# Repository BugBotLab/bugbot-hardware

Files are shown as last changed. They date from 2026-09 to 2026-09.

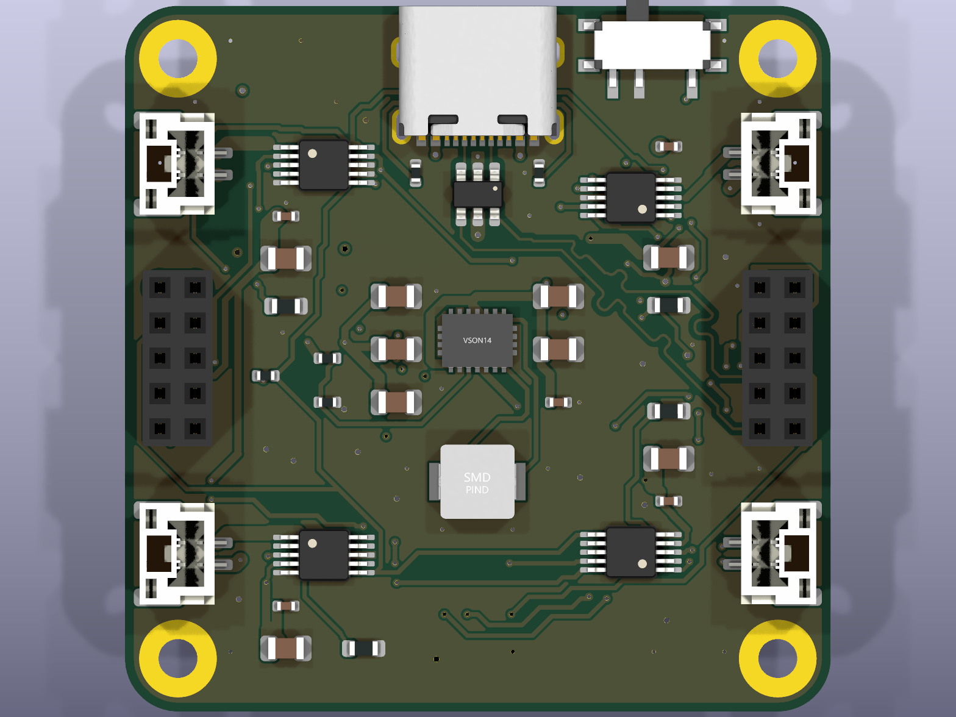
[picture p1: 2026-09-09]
design/3d/BugBot_Motion_Board_top.png

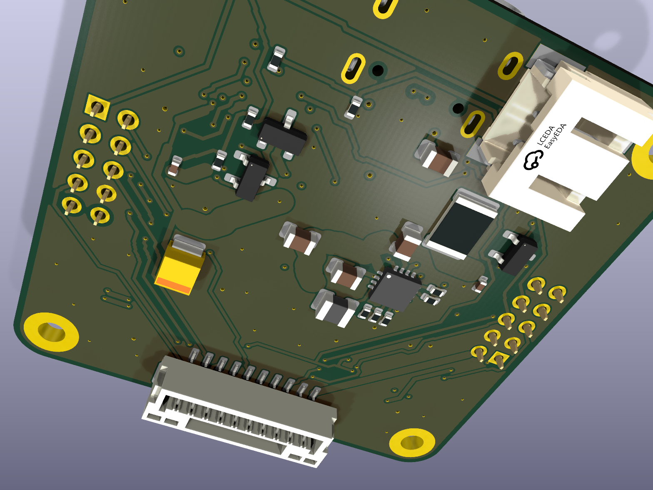
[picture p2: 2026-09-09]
design/3d/BugBot_Motion_Board_iso_bottom.png

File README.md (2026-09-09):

# bugbot-hardware

Everything physical about BugBot: the schematics, the bill of materials, 3D models of the robot and its boards, the assembly guide, and the circuit simulation bench that doubles as the schematics' test suite.

Part of the [BugBot open-source plan](https://github.com/BugBotLab).

## What is public and what is not

The **schematics are public**: every sheet as KiCad source and as PDF, the symbol library, the netlists, and the BOM with part numbers. Anyone can read, simulate and repair every circuit.

The **PCB layout is not published**: no `.kicad_pcb`, no gerbers, no pick-and-place files. The 3D models here were exported without copper, so they show the boards and their parts but not the routing.

## The robot

Three 40 x 40 mm boards stacked on 2 x 5 sockets, on a 3D-printed chassis, moving by four vibration motors on a silicone mat:

| Board | Does |
|---|---|
| Motion | battery, USB-C charging, 3.3 V rail, four DRV8830 motor drivers, two servo outputs, the ToF module connector |
| Vision | ESP32-P4 (plus its C6 for Wi-Fi), OV5647 camera on a 22-pin flex, power switch, boot and reset buttons, LED |
| Odometry | PMW3360 optical-flow sensor and BNO055 IMU, on a 10-way cable to Motion |

## Layout

| path | what |
|---|---|
| `design/schematics/<Board>/` | KiCad schematic sheets, `BugBot.kicad_sym`, the project file, `golden_netlist.xml`, and the schematic PDF |
| `design/bom/` | `BugBot_BOM.xlsx` (parts, per-board sheets, costing, flags) and the JLCPCB BOM CSVs |
| `design/3d/` | `.step` and `.glb` of each board without copper, plus renders |
| `design/mechanical/` | chassis and mat (see its README for where the CAD lives today) |
| `sim/` | the circuit bench: ngspice simulation of the whole stack from the netlists, 89 static checks, scenario runs, and an interactive schematic bench. See `sim/README.md` |
| `docs/` | assembly and bring-up |
| `viewer/` | a web page that spins the board models (uses the `.glb` files), hosted at https://www.bugbotlab.com/bugbot-hardware/viewer/ |

## Simulation is the schematic test suite

`sim/` builds a SPICE model of the three boards from `golden_netlist.xml` and checks it against the datasheets: rails, currents, USB limits, no-cell behaviour, motor stalls. When a schematic changes, `python sim/tools/sync_boards.py` refreshes the snapshot and `python sim/check_static.py` plus `python sim/sim_stack.py` say whether it still holds. That is why the bench lives in this repo rather than beside the firmware.

Needs KiCad 10 installed (for ngspice and kicad-cli).

## Licence

MIT, BugBotLab Ltd. Hardware files under the same licence.

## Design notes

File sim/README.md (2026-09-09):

# bugbot_sim

Circuit simulation of the BugBot stack (Motion board + Vision board + Odometry
board) from the real KiCad netlists, using KiCad's bundled ngspice. Every
component value and every connection comes from `golden_netlist.xml`; the ICs
are behavioural models built from their datasheets (`models/stack_models.lib`,
numbers and sources in `parts_spec.py`). Motors are electromechanical, the MCU
is a scripted list of I2C register writes. The Motion and Vision boards join
pin-for-pin at the J8/J9 stack sockets; the Odometry board hangs on the Motion
J7 GH1.25 cable (J7 pin k to J1 pin 11-k since the 2026-09-07 mirror, 120 mOhm per conductor) with its 1.9 V LDO,
the PMW3360 and the BNO055 modelled as loads (added 2026-09-06).

## Run

```
python sim_stack.py        # scenarios A-P (DC, transient, no-cell, USB limits) + datasheet spec checks (~2 min)
python sim_mission.py      # drive / stall / USB missions with running motors (~3 min)
MOTOR=N20_geared_3v python sim_mission.py     # other motor types: see parts_spec.MOTOR_TYPES
python bench/server.py     # interactive schematic bench at http://localhost:8765
python tools/sync_boards.py   # refresh boards/ from the KiCad projects (BUGBOT_HW env)
```

Needs KiCad 10 installed (ngspice.dll, kicad-cli, symbol library). Override with
`NGSPICE_DLL` or `KICAD_DIR`.

## Layout

| path | what |
|---|---|
| `boards/<motion,vision,odometry>/` | snapshot of each project: golden netlist, schematic sheets, sheet SVGs |
| `models/` | SPICE behavioural models (`stack_models.lib` is the current one) |
| `netlist2spice.py` | golden netlist -> SPICE elements, the only source of connectivity |
| `stack_build.py` | the shared deck: Motion + Vision joined at J8/J9, Odometry on the J7 cable, loads, motors, servos |
| `parts_spec.py` | datasheet limits per part, motor types |
| `sim_stack.py` | scenarios A..M and spec checks, prints DESIGN FINDINGS |
| `sim_mission.py` | time-domain missions, writes `out/mission_*.json` |
| `sch_geometry.py` | every wire / pin of every sheet tied to its net (for the bench) |
| `bench/` | interactive viewer: click the switch, USB, motors; ngspice re-solves |
| `legacy/` | the first single-board testbenches (pre-respin Motion, Vision only) |

## Field solver

The openEMS field-solver experiments (impedance and emissions from the PCB layout) are not in this repository: they work from the layout files, which are not published.

## What the simulation can and cannot see

`sim_stack.py` starts with `check_static.py`: every IC pin against its
CONFIRMED datasheet pin table (`parts_spec.PARTS[...]["pinout"]`), the
DRV8830 address straps (unique addresses), the I2C pull-ups, the FB divider,
the charger's ENB/USB_DET/ENPPB/ISET straps, floating inputs. This exists
because the DRV8830 pinout error of 2026-09-04 passed every ngspice scenario:
the sim and the schematic shared the same wrong pin table. A netlist-driven
sim proves board = schematic, not schematic = datasheet.

Still approximate, on purpose:
- the regulators and the H-bridges are average (non-switching) models; the
  inductor checks add the 2.4 MHz / 3 MHz ripple analytically, capacitor
  ripple current is not checked
- an operating point that ngspice cannot converge is taken from a ramped
  transient and counted in the summary line ("N operating point(s) from
  ramped transients"); a real instability would look the same
- the PTC is a resistor: the harness checks the cell current against its
  3 A hold, it never trips in the model
- loads are constant currents except the Wi-Fi burst scenario (N) and the
  missions; the ToF and camera are their typical currents; the Odometry
  board's PMW3360 draws the datasheet's run4 figure (37 mA including the
  LED, PixArt v1.30 Table 5), the BNO055 its 12.3 mA NDOF figure
- numbers still to measure: motor winding resistance, HK-5320 servo currents,
  I2C bus capacitance (~90 pF estimate)

## Current findings

See the DESIGN FINDINGS block printed by `sim_stack.py`. As of 2026-09-04:
the DRV8830s drop below their 2.75 V UVLO on a 3.0 V cell (firmware cut-off
near 3.3 V), and charging at 806 mA while running draws 1.36 A from USB
(needs a 1.5 A-advertising source, or USB_DET/ISET2 for weak ports).

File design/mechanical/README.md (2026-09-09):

# Mechanical

Chassis, mat and printed parts.

Today the CAD lives in BugBotLab's cloud drive (`Mech Design`), not yet in this repo. It moves here as STEP plus the printable STL/3MF files once the new three-board stack has been fitted to the chassis (the stack is 7.1 mm between boards with 5.6 mm sockets).

What belongs here when it lands:

- `chassis/` the printed frame that carries the three boards, the four motors and the battery
- `mat/` the silicone mat and any printed marker layout (AprilTags for absolute position)
- `print/` ready-to-print files with the print settings used

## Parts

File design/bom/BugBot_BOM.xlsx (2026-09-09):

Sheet: Summary
BugBot stack BOM
Source: KiCad schematic netlists (golden, after the 2026-09-07 rework); LCSC fields; stock, price and part class read from jlcpcb.com part pages on 2026-09-06 (rework parts on 2026-09-07).
Yellow cells are inputs you can change. Everything else is a formula.
Boards to build (sets) | 5
USD per GBP | 1.27
JLC extended-part fee per line, USD | 3
Thin-stock threshold (pieces) | 5000
Board | Lines | Parts per board | JLC parts cost per board (USD) | Extended lines | Extended fee per order (USD) | Parts cost per set of boards (USD) | Parts cost per set (GBP) | Lines with no JLC code | Lines below thin-stock | Lines short for the run
BugBot Motion Board | 30 | 63 | $16.63 | 18 | $54.00 | $83.16 | £65.48 | 2 | 3 | 0
BugBot Vision Board | 15 | 27 | $1.20 | 5 | $15.00 | $5.99 | £4.72 | 3 | 1 | 0
BugBot Odometry Board | 13 | 23 | $9.99 | 3 | $9.00 | $49.95 | £39.33 | 1 | 1 | 0
Stack (one of each) | 58 | 113 | $27.82 | 26 | $78.00 | $139.11 | £109.53 | 6 | 5 | 0
Parts cost per robot, GBP (JLC parts only, no PCB, assembly, or the three hand-soldered parts) | £21.91
Extended-part fees for one order of all three boards, USD | $78.00
Not on JLC (bought and hand-soldered): Motion J8/J9 and Vision J8/J9 2x5 2.00 mm stack connectors, Vision U3 ESP32-P4 module, Odometry U2 PMW3360 sensor + LM19 lens. Mounting holes H1-H4 have no part.
Thin stock on the day: DRV8830 (C127591) 129 pcs = 32 Motion boards; camera 22P top-contact connector (C2911765) 473; GH1.25 10-pin (C3029376) 1,796; ETA6003 (C5455585) 2,234. Nothing was pre-order or idle.
Rework 2026-09-07: switch SW3 now on Vision (underside, top edge); servo connectors J10/J11 (side-entry GH1.25 3P) back on Motion; ToF J7 side-entry on the Vision underside; camera J3 = 22P 0.5 mm top-contact horizontal for the OV5647 spy module (pinout mirrored: pin k = Pi Zero pin 23-k). See the Flags sheet for the open items and the decisions taken.

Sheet: Costing
Order costing for the run (JLCPCB fees from jlcpcb.com/help/article/pcb-assembly-price and the quote form, read 2026-09-09)
Yellow cells are inputs. Board part counts and Extended-line counts come from the board sheets; parts cost from the Summary sheet.
Sets to build | 5 | sets, from the Summary sheet
USD per GBP | 1.27 | from the Summary sheet
PCB price, 4-layer 40x40 mm, 5 pcs (USD) | 7 | quote form 2026-09-09, JLC04161H-3313 stackup, ENIG adds ~$15 per order
Economic assembly setup (USD) | $8.18 | top side only
Economic stencil (USD) | $1.53
Economic feeder fee per Extended part type (USD) | $3.07 | Basic parts free
Standard both-sides setup (USD) | $51.12 | needed when parts sit on both sides
Standard both-sides stencil (USD) | $16.42
Standard feeder fee per part type (USD) | $1.53 | Basic and Extended
Solder joint (USD) | $0.0016 | per joint; about 2.5 joints per part on these boards
Shipping, DHL Express DDP incl. duties and VAT (USD) | $28.00 | one parcel, quote form estimate for ~0.25 kg
ACTUAL JLC invoice, all orders incl. parts and shipping (USD) | $420.93 | invoice 2444722A2026090908545474 of 09/09/2026: per-order totals in column K, shipping K21, discount B16; the totals below use it instead of the estimate
JLC discount on the invoice (USD, negative) | -$19.38 | invoice line 'Discount'
Board | Assembly type | JLC lines | Extended lines | Parts per board | Setup + stencil (USD) | Feeder fees (USD) | Joints (USD) | PCB (USD) | Board order estimate (USD) | ACTUAL order total incl. parts (USD) | JLC order number
BugBot Motion Board | Standard both sides | 28 | 18 | 61 | $67.54 | $42.84 | $1.22 | $7.00 | $118.60 | $200.34 | SMT026090960104-Y13
BugBot Vision Board | Economic top only | 12 | 5 | 24 | $9.71 | $15.35 | $0.48 | $7.00 | $32.54 | $103.67 | SMT026090960086-Y12
BugBot Odometry Board | Economic top only | 12 | 3 | 22 | $9.71 | $9.21 | $0.44 | $7.00 | $26.36 | $112.40 | SMT026090960075-Y11
 |  |  |  |  |  |  |  |  | Actual shipping, DHL Express (USD) | $23.90
JLC assembly and PCBs, three orders (USD) | $177.50
JLC components for the run (USD, Summary sheet) | $139.11
Shipping (USD) | $28.00
JLC total, estimate (USD) | $344.61
JLC total used below: actual invoice if entered, else the estimate (USD) | $420.93
JLC total used below (GBP) | £331.44 |  |  |  | Vision underside parts hand-soldered by you for the Economic option: C20, C21, J7 (ToF), SW3 (switch).
Actual minus estimate (USD) | $76.32
Bought elsewhere (per robot) | Qty per robot | Unit price (USD) | Per robot (USD) | For the run (USD) | Note
ESP32-P4 module (Waveshare) | 1 | $20.00 | $20.00 | $100.00 | Vision U3, hand-soldered
OV5647 spy camera, 120 deg, 22-pin flex | 1 | $8.00 | $8.00 | $40.00 | or Pi Zero camera board + short cable
VL53L5CX ToF module + 6-way GH cable | 1 | $8.00 | $8.00 | $40.00 | cable to the board's pin order
PMW3360 sensor + LM19 lens | 1 | $15.00 | $15.00 | $75.00 | Odometry U2
2x5 2.00 mm socket 5.6 mm + header | 2 | $1.00 | $2.00 | $10.00 | stack, hand-soldered
GH1.25 10-way REVERSE cable | 1 | $1.50 | $1.50 | $7.50 | cavity 1 to cavity 10
1S LiPo 450 mAh 25C (Syma type) | 1 | $4.00 | $4.00 | $20.00 | or 2 in parallel
0615 coreless motor | 4 | $2.00 | $8.00 | $40.00
HK-5320 servo | 2 | $6.00 | $12.00 | $60.00
WS2812 LED ball | 1 | $1.00 | $1.00 | $5.00
Bought elsewhere, per robot (USD) | $79.50
Bought elsewhere, for the run (USD) | $397.50
TOTAL for the run (USD) | $818.43
TOTAL for the run (GBP) | £644.43
Per robot (GBP) | £128.89
Prices for the bought-elsewhere parts are estimates typed in as inputs; replace them with what you actually pay. JLC component prices are the 1-piece prices; at 5 sets JLC usually comes out a little lower.

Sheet: Parts
Unique JLC parts across the three boards. Stock, price (1-piece, USD) and class read live from jlcpcb.com on 2026-09-06 (2026-09-07 for the rework parts). None were idle / pre-order.
LCSC | MPN | Manufacturer | JLC description | Class | Stock | Unit price (USD) | Pre-order / idle | Checked | Total used per set | Needed for run | Stock status | Datasheet
C127591 | DRV8830DGQR | Texas Instruments | -40℃~+85℃ 1 1A 1A 2.75V~6.8V 300nA 450mΩ I2C Yes MSOP-10-EP Brushed DC Motor Drivers ROHS | Extended | 129 | $2.7355 | No | 2026-09-06 | 4 | 20 | Thin | https://www.ti.com/lit/ds/symlink/drv8830.pdf
C1525 | CL05B104KO5NNNC | Samsung | 100nF 16V X7R ±10% 0402 Multilayer Ceramic Capacitors MLCC - SMD/SMT ROHS | Basic | 37375769 | $0.0051 | No | 2026-09-06 | 14 | 70 | OK | https://jlcpcb.com/partdetail/C1525
C15483 | TPS63020DSJR | Texas Instruments | -40℃~+85℃@(TA) 1 1.2V~5.5V 1.8V~5.5V 2.4MHz 3A 50uA Adjustable Buck-Boost Buck-Boost Built-in Yes VSON-14-EP(3 | Extended | 13311 | $0.9584 | No | 2026-09-06 | 1 | 5 | OK | https://www.ti.com/lit/ds/symlink/tps63020.pdf
C15850 | CL21A106KAYNNNE | Samsung | 10uF 25V X5R ±10% 0805 Multilayer Ceramic Capacitors MLCC - SMD/SMT ROHS | Basic | 7849987 | $0.0847 | No | 2026-09-06 | 13 | 65 | OK | https://jlcpcb.com/partdetail/C15850
C1653 | CL10C220JB8NNNC | Samsung | 22pF 50V C0G 0603 ±5% Multilayer Ceramic Capacitors MLCC - SMD/SMT | Basic | 2640152 | $0.0068 | No | 2026-09-07 | 2 | 10 | OK | https://jlcpcb.com/partdetail/C1653
C19666 | CL10A475KO8NNNC | Samsung | 16V 4.7uF X5R ±10% 0603 Multilayer Ceramic Capacitors MLCC - SMD/SMT ROHS | Basic | 4016851 | $0.0333 | No | 2026-09-06 | 1 | 5 | OK | https://jlcpcb.com/partdetail/C19666
C20627123 | 1812L300/24GR | LUTE | -40℃~+85℃ 1.4W 1.5mm 10mΩ 24V 3.41mm 3A 4.73mm 40A 4s 5A 60mΩ 1812 Resettable Fuses ROHS | Extended | 53558 | $0.1384 | No | 2026-09-06 | 1 | 5 | OK | https://jlcpcb.com/partdetail/C20627123
C25076 | 0402WGF1000TCE | UNI-ROYAL | -55℃~+155℃ 100Ω 50V 62.5mW Thick Film Resistor ±1% ±100ppm/℃ 0402 Chip Resistor - Surface Mount ROHS | Basic | 3999877 | $0.0037 | No | 2026-09-06 | 1 | 5 | OK | https://jlcpcb.com/partdetail/C25076
C25105 | 0402WGF330JTCE | UNI-ROYAL | 33Ω 62.5mW 0402 ±1% Chip Resistor - Surface Mount | Basic | 2403330 | $0.0041 | No | 2026-09-07 | 1 | 5 | OK | https://jlcpcb.com/partdetail/C25105
C25741 | 0402WGF1003TCE | UNI-ROYAL | -55℃~+155℃ 100kΩ 50V 62.5mW Thick Film Resistor ±1% ±100ppm/℃ 0402 Chip Resistor - Surface Mount ROHS | Basic | 12874055 | $0.0028 | No | 2026-09-06 | 3 | 15 | OK | https://jlcpcb.com/partdetail/C25741
C25744 | 0402WGF1002TCE | UNI-ROYAL | -55℃~+155℃ 10kΩ 50V 62.5mW Thick Film Resistor ±1% ±100ppm/℃ 0402 Chip Resistor - Surface Mount ROHS | Basic | 30863902 | $0.0031 | No | 2026-09-06 | 10 | 50 | OK | https://jlcpcb.com/partdetail/C25744
C25760 | 0402WGF1803TCE | UNI-ROYAL | -55℃~+155℃ 180kΩ 50V 62.5mW Thick Film Resistor ±1% ±100ppm/℃ 0402 Chip Resistor - Surface Mount ROH | Extended | 229024 | $0.0020 | No | 2026-09-06 | 1 | 5 | OK | https://jlcpcb.com/partdetail/C25760
C25779 | 0402WGF3302TCE | UNI-ROYAL | 33kΩ 62.5mW 0402 ±1% Chip Resistor - Surface Mount | Basic | 1512746 | $0.0092 | No | 2026-09-07 | 1 | 5 | OK | https://jlcpcb.com/partdetail/C25779
C25792 | 0402WGF4702TCE | UNI-ROYAL | -55℃~+155℃ 47kΩ 50V 62.5mW Thick Film Resistor ±1% ±100ppm/℃ 0402 Chip Resistor - Surface Mount ROHS | Basic | 6406298 | $0.0029 | No | 2026-09-06 | 2 | 10 | OK | https://jlcpcb.com/partdetail/C25792
C25879 | 0402WGF2201TCE | UNI-ROYAL | -55℃~+155℃ 2.2kΩ 50V 62.5mW Thick Film Resistor ±1% ±100ppm/℃ 0402 Chip Resistor - Surface Mount ROH | Basic | 1612344 | $0.0039 | No | 2026-09-06 | 2 | 10 | OK | https://jlcpcb.com/partdetail/C25879
C25905 | 0402WGF5101TCE | UNI-ROYAL | -55℃~+155℃ 5.1kΩ 50V 62.5mW Thick Film Resistor ±1% ±100ppm/℃ 0402 Chip Resistor - Surface Mount ROH | Basic | 8102286 | $0.0026 | No | 2026-09-06 | 2 | 10 | OK | https://jlcpcb.com/partdetail/C25905
C26083 | 0402WGF1004TCE | UNI-ROYAL | -55℃~+155℃ 1MΩ 50V 62.5mW Thick Film Resistor ±1% ±100ppm/℃ 0402 Chip Resistor - Surface Mount ROHS | Basic | 3167975 | $0.0026 | No | 2026-09-06 | 2 | 10 | OK | https://jlcpcb.com/partdetail/C26083
C2687116 | USBLC6-2SC6 | UMW | 0.35pF、0.8pF 100nA 150W@8/20us 15V 2 5V 6A@8/20us 6V ESD SOT-23-6 ESD and Surge Protection (TVS/ESD) | Extended | 79405 | $0.0475 | No | 2026-09-06 | 1 | 5 | OK | https://jlcpcb.com/partdetail/C2687116
C274889 | RC0402FR-071K24L | YAGEO | -55℃~+155℃ 1.24kΩ 50V 62.5mW Thick Film Resistor ±1% ±100ppm/℃ 0402 Chip Resistor - Surface Mount RO | Extended | 94104 | $0.0026 | No | 2026-09-06 | 1 | 5 | OK | https://jlcpcb.com/partdetail/C274889
C2765186 | TYPE-C 16PIN 2MD(073) | SHOU HAN | -25℃~+85℃ 1 16P 3A 5,000 times 5V Black Female Surface Mount, Right Angle Type-C SMD USB Connectors | Extended | 995015 | $0.0743 | No | 2026-09-06 | 1 | 5 | OK | https://jlcpcb.com/partdetail/C2765186
C2911765 | 0.5K-AS-22PWB | HDGC | 22P 0.5mm pitch top-contact horizontal FFC/FPC connector (camera flex) | Extended | 473 | $0.1355 | No | 2026-09-07 | 1 | 5 | Thin | https://jlcpcb.com/partdetail/C2911765
C2934253 | FRL0603FR500TS | FOJAN | -55℃~+155℃ 100V 100mW 500mΩ Thick Film Resistor ±1% ±300ppm/℃ 0603 Chip Resistor - Surface Mount ROH | Extended | 202425 | $0.0054 | No | 2026-09-06 | 4 | 20 | OK | https://jlcpcb.com/partdetail/C2934253
C295747 | S2B-PH-SM4-TB(LF)(SN) | JST | -25℃~+85℃ 1 100V 1x2P 2 2A 2P 2mm 5.5mm 7.9mm 8.6mm Auxiliary Solder Pin Beige Copper alloy PA PH Su | Extended | 29773 | $0.2396 | No | 2026-09-06 | 1 | 5 | OK | https://jlcpcb.com/partdetail/C295747
C3029368 | WAFER-GH1.25-2PLB | XUNPU | -25℃~+85℃ 1 1.25mm 125V 1A 1x2P 2 2P 4.2mm 4.95mm 5.75mm Auxiliary Solder Pin Beige Brass GH LCP Sur | Extended | 46600 | $0.1300 | No | 2026-09-06 | 4 | 20 | OK | https://jlcpcb.com/partdetail/C3029368
C3029369 | WAFER-GH1.25-3PLB | XUNPU | -25℃~+85℃ 1 1.25mm 125V 1A 1x3P 3 3P 4.2mm 4.95mm 7mm Auxiliary Solder Pin Beige Brass GH LCP Surfac | Extended | 15257 | $0.1467 | No | 2026-09-06 | 1 | 5 | OK | https://jlcpcb.com/partdetail/C3029369
C3029376 | WAFER-GH1.25-10PLB | XUNPU | -25℃~+85℃ 1 1.25mm 10 10P 125V 15.75mm 1A 1x10P 4.2mm 4.95mm Auxiliary Solder Pin Beige Brass GH LCP | Extended | 1796 | $0.2164 | No | 2026-09-06 | 2 | 10 | Thin | https://jlcpcb.com/partdetail/C3029376
C3029378 | WAFER-GH1.25-3PWB | XUNPU | GH1.25 3P side-entry (horizontal) SMD wafer, 1.25mm pitch | Extended | 78982 | $0.1243 | No | 2026-09-07 | 2 | 10 | OK | https://jlcpcb.com/partdetail/C3029378
C3029381 | WAFER-GH1.25-6PWB | XUNPU | GH1.25 6P side-entry (horizontal) SMD wafer, 1.25mm pitch | Extended | 32531 | $0.1605 | No | 2026-09-07 | 1 | 5 | OK | https://jlcpcb.com/partdetail/C3029381
C32346 | Q13FC13500004 | Seiko Epson | -40℃~+85℃ 12.5pF 32.768kHz 70kΩ Crystal Oscillator ±20ppm SMD3215-2P Crystals ROHS | Basic | 761776 | $0.1714 | No | 2026-09-06 | 1 | 5 | OK | https://jlcpcb.com/partdetail/C32346
C344008 | SI2333 | BORN | -55℃~+150℃ 1 P-Channel 1.25W 12V 1V 5.1A 59mΩ@1.8V 920pF SOT-23 MOSFETs ROHS | Extended | 28583 | $0.0619 | No | 2026-09-06 | 3 | 15 | OK | https://www.vishay.com/docs/68868/si2333dds.pdf
C408335 | MWSA0402S-2R2MT | Sunlord | 2.2uH 4.5A 58mΩ 5A ±20% SMD,4.4x4.2mm Power Inductors ROHS | Extended | 33271 | $0.1524 | No | 2026-09-06 | 1 | 5 | OK | https://jlcpcb.com/partdetail/C408335
C4109 | 0402WGF2001TCE | UNI-ROYAL | -55℃~+155℃ 2kΩ 50V 62.5mW Thick Film Resistor ±1% ±100ppm/℃ 0402 Chip Resistor - Surface Mount ROHS | Basic | 8265751 | $0.0029 | No | 2026-09-06 | 1 | 5 | OK | https://jlcpcb.com/partdetail/C4109
C431540 | MSK12C02 | SHOU HAN | -20℃~+70℃ 1.4mm 10000 times 12V 2.8mm 50mA 8mm SMD(SMT) Tab SPDT Surface Mount, Right Angle SMD,8x2. | Extended | 150031 | $0.0566 | No | 2026-09-06 | 1 | 5 | OK | https://jlcpcb.com/partdetail/C431540
C45783 | CL21A226MAQNNNE | Samsung | 22uF 25V X5R ±20% 0805 Multilayer Ceramic Capacitors MLCC - SMD/SMT ROHS | Basic | 5276598 | $0.2492 | No | 2026-09-06 | 5 | 25 | OK | https://jlcpcb.com/partdetail/C45783
C52923 | CL05A105KA5NQNC | Samsung | 1uF 25V X5R ±10% 0402 Multilayer Ceramic Capacitors MLCC - SMD/SMT ROHS | Basic | 10724896 | $0.0121 | No | 2026-09-06 | 7 | 35 | OK | https://jlcpcb.com/partdetail/C52923
C5455585 | ETA6003Q3Q | etasolution | -40℃~+85℃ 1 2A 4.2V 4.4V~5.5V 70uA Charging IC Lithium Battery Support Support QFN3X3-16 Battery Man | Extended | 2234 | $0.5182 | No | 2026-09-06 | 1 | 5 | Thin | https://jlcpcb.com/partdetail/C5455585
C5832356 | FTC252010S1R0MBCA | cjiang | 1uH 25mΩ 4.5A 5.3A ±20% 1008 Molding Power Inductors ROHS | Extended | 263367 | $0.0278 | No | 2026-09-06 | 1 | 5 | OK | https://jlcpcb.com/partdetail/C5832356
C7196 | TAJB107M010RNJ | AVX | -55℃~+125℃ 1.4Ω@100kHz 100uF 10V ±20% CASE-B-3528-21(mm) Tantalum Capacitors ROHS | Extended | 147504 | $0.4874 | No | 2026-09-06 | 1 | 5 | OK | https://jlcpcb.com/partdetail/C7196
C7470171 | ZX-QC4545-4.3TP | Megastar | -30℃~+80℃ 100,000 cycles 12V 2.6N 4.3mm 4.5mm 4.5mm 50mA Black Gull Wing Round Button SPST Surface M | Extended | 25261 | $0.0251 | No | 2026-09-06 | 2 | 10 | OK | https://jlcpcb.com/partdetail/C7470171
C93216 | BNO055 | Bosch Sensortec | -40℃~+85℃ 2.4V~3.6V 40uA I2C、UART IMU X,Y,Z X,Y,Z ±16g ±2000dps LGA-28(3.8x5.2) Accelerometers ROHS | Extended | 8957 | $9.3239 | No | 2026-09-06 | 1 | 5 | OK | https://www.bosch-sensortec.com/media/boschsensortec/downloads/datasheets/bst-bno055-ds000.pdf
C95939 | SDNT1005X103F3950FTF | Sunlord | -55℃~+125℃ 0.5mm 0.5mm 100mW 10kΩ 1mW/℃ 1mm 330uA 3950K 3s ±1% ±1% 0402 NTC Thermistors ROHS | Extended | 73099 | $0.0166 | No | 2026-09-06 | 1 | 5 | OK | https://jlcpcb.com/partdetail/C95939
C96343 | AP2127K-ADJTRG1 | Diodes Inc | -40℃~+85℃ 1 300mA 300mV@(300mA) 45dB@(10kHz)、68dB@(100Hz) 60uA 60uVrms 800mV~5.5V 9V Adjustable Over | Extended | 50060 | $0.1269 | No | 2026-09-06 | 1 | 5 | OK | https://www.diodes.com/assets/Datasheets/AP2127.pdf

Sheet: Motion
BugBot Motion Board BOM (per board). Refs and quantities from Motion_sch_netlist.xml; prices and stock via the Parts sheet.
Refs | Qty | Value | Footprint | LCSC | MPN | Class | Stock | Unit price (USD) | Line cost (USD) | Source / status | Stock status | Datasheet
C1, C2, C6, C8, C14, C16, C18, C20, C23 | 9 | 10u | Capacitor_SMD:C_0805_2012Metric | C15850 | CL21A106KAYNNNE | Basic | 7849987 | $0.0847 | $0.76 | JLC assembly | OK | https://jlcpcb.com/partdetail/C15850
C4 | 1 | 1u | Capacitor_SMD:C_0402_1005Metric | C52923 | CL05A105KA5NQNC | Basic | 10724896 | $0.0121 | $0.01 | JLC assembly | OK | https://jlcpcb.com/partdetail/C52923
C5, C9, C21, C22 | 4 | 22u | Capacitor_SMD:C_0805_2012Metric | C45783 | CL21A226MAQNNNE | Basic | 5276598 | $0.2492 | $1.00 | JLC assembly | OK | https://jlcpcb.com/partdetail/C45783
C7, C13, C15, C17, C19, C24 | 6 | 100n | Capacitor_SMD:C_0402_1005Metric | C1525 | CL05B104KO5NNNC | Basic | 37375769 | $0.0051 | $0.03 | JLC assembly | OK | https://jlcpcb.com/partdetail/C1525
CB1 | 1 | 100u | Capacitor_Tantalum_SMD:CP_EIA-3528-21_Kemet-B | C7196 | TAJB107M010RNJ | Extended | 147504 | $0.4874 | $0.49 | JLC assembly | OK | https://jlcpcb.com/partdetail/C7196
F1 | 1 | 3A/6A PTC | Fuse:Fuse_1812_4532Metric | C20627123 | 1812L300/24GR | Extended | 53558 | $0.1384 | $0.14 | JLC assembly | OK | https://jlcpcb.com/partdetail/C20627123
J1 | 1 | USB-C 16P | jlc:USB-C-SMD_TYPE-C-16PIN-2MD-073 | C2765186 | TYPE-C 16PIN 2MD(073) | Extended | 995015 | $0.0743 | $0.07 | JLC assembly | OK | https://jlcpcb.com/partdetail/C2765186
J2 | 1 | JST-PH 2P batt | jlc:CONN-SMD_P2.00_S2B-PH-SM4-TB-LF-SN | C295747 | S2B-PH-SM4-TB(LF)(SN) | Extended | 29773 | $0.2396 | $0.24 | JLC assembly | OK | https://jlcpcb.com/partdetail/C295747
J3, J4, J5, J6 | 4 | Motor A GH2 | Connector_JST:JST_GH_BM02B-GHS-TBT_1x02-1MP_P1.25mm_Vertical | C3029368 | WAFER-GH1.25-2PLB | Extended | 46600 | $0.1300 | $0.52 | JLC assembly | OK | https://jlcpcb.com/partdetail/C3029368
J7 | 1 | Optical flow + IMU GH10 | Connector_JST:JST_GH_BM10B-GHS-TBT_1x10-1MP_P1.25mm_Vertical | C3029376 | WAFER-GH1.25-10PLB | Extended | 1796 | $0.2164 | $0.22 | JLC assembly | Thin | https://jlcpcb.com/partdetail/C3029376
J10, J11 | 2 | Servo 1 GH1.25 3P side-entry | Connector_JST:JST_GH_SM03B-GHS-TB_1x03-1MP_P1.25mm_Horizontal | C3029378 | WAFER-GH1.25-3PWB | Extended | 78982 | $0.1243 | $0.25 | JLC assembly | OK | https://jlcpcb.com/partdetail/C3029378
L1 | 1 | 1uH 4.5A | Inductor_SMD:L_1008_2520Metric | C5832356 | FTC252010S1R0MBCA | Extended | 263367 | $0.0278 | $0.03 | JLC assembly | OK | https://jlcpcb.com/partdetail/C5832356
L2 | 1 | 2.2u | jlc:IND-SMD_L4.4-W4.2 | C408335 | MWSA0402S-2R2MT | Extended | 33271 | $0.1524 | $0.15 | JLC assembly | OK | https://jlcpcb.com/partdetail/C408335
Q1, Q2, Q3 | 3 | SI2333 | Package_TO_SOT_SMD:SOT-23 | C344008 | SI2333 | Extended | 28583 | $0.0619 | $0.19 | JLC assembly | OK | https://www.vishay.com/docs/68868/si2333dds.pdf
R1, R2 | 2 | 5k1 Rd | Resistor_SMD:R_0402_1005Metric | C25905 | 0402WGF5101TCE | Basic | 8102286 | $0.0026 | $0.01 | JLC assembly | OK | https://jlcpcb.com/partdetail/C25905
R3, R18 | 2 | 10k | Resistor_SMD:R_0402_1005Metric | C25744 | 0402WGF1002TCE | Basic | 30863902 | $0.0031 | $0.01 | JLC assembly | OK | https://jlcpcb.com/partdetail/C25744
R4, R9, R10 | 3 | 100k | Resistor_SMD:R_0402_1005Metric | C25741 | 0402WGF1003TCE | Basic | 12874055 | $0.0028 | $0.01 | JLC assembly | OK | https://jlcpcb.com/partdetail/C25741
R5 | 1 | 1k24 | Resistor_SMD:R_0402_1005Metric | C274889 | RC0402FR-071K24L | Extended | 94104 | $0.0026 | $0.0026 | JLC assembly | OK | https://jlcpcb.com/partdetail/C274889
R6 | 1 | 2k | Resistor_SMD:R_0402_1005Metric | C4109 | 0402WGF2001TCE | Basic | 8265751 | $0.0029 | $0.0029 | JLC assembly | OK | https://jlcpcb.com/partdetail/C4109
R7 | 1 | 47k | Resistor_SMD:R_0402_1005Metric | C25792 | 0402WGF4702TCE | Basic | 6406298 | $0.0029 | $0.0029 | JLC assembly | OK | https://jlcpcb.com/partdetail/C25792
R8, R16 | 2 | 1M | Resistor_SMD:R_0402_1005Metric | C26083 | 0402WGF1004TCE | Basic | 3167975 | $0.0026 | $0.01 | JLC assembly | OK | https://jlcpcb.com/partdetail/C26083
R17 | 1 | 180k | Resistor_SMD:R_0402_1005Metric | C25760 | 0402WGF1803TCE | Extended | 229024 | $0.0020 | $0.002 | JLC assembly | OK | https://jlcpcb.com/partdetail/C25760
R19, R20, R21, R22 | 4 | 0R5 | Resistor_SMD:R_0603_1608Metric | C2934253 | FRL0603FR500TS | Extended | 202425 | $0.0054 | $0.02 | JLC assembly | OK | https://jlcpcb.com/partdetail/C2934253
RT1 | 1 | 10k B3950 | Resistor_SMD:R_0402_1005Metric | C95939 | SDNT1005X103F3950FTF | Extended | 73099 | $0.0166 | $0.02 | JLC assembly | OK | https://jlcpcb.com/partdetail/C95939
U1 | 1 | ETA6003Q3Q | jlc:QFN-16_L3.0-W3.0-P0.50-TL-EP1.7-2 | C5455585 | ETA6003Q3Q | Extended | 2234 | $0.5182 | $0.52 | JLC assembly | Thin | https://jlcpcb.com/partdetail/C5455585
U3 | 1 | TPS63020DSJ | jlc:VSON-14_L4.0-W3.0-P0.50-BL-EP_TI_DSJ | C15483 | TPS63020DSJR | Extended | 13311 | $0.9584 | $0.96 | JLC assembly | OK | https://www.ti.com/lit/ds/symlink/tps63020.pdf
U5 | 1 | USBLC6-2SC6 | Package_TO_SOT_SMD:SOT-23-6 | C2687116 | USBLC6-2SC6 | Extended | 79405 | $0.0475 | $0.05 | JLC assembly | OK | https://jlcpcb.com/partdetail/C2687116
U6, U7, U8, U9 | 4 | DRV8830DGQR | Package_SO:MSOP-10-1EP_3x3mm_P0.5mm_EP1.68x1.88mm | C127591 | DRV8830DGQR | Extended | 129 | $2.7355 | $10.94 | JLC assembly | Thin | https://www.ti.com/lit/ds/symlink/drv8830.pdf
J8 | 1 | Stack A 2x5 socket | Connector_PinSocket_2.00mm:PinSocket_2x05_P2.00mm_Vertical |  |  |  |  | $0.0000 | $0.00 | 2x5 2.00 mm socket, hand-soldered (AliExpress/Farnell) | n/a
J9 | 1 | Stack B 2x5 socket | Connector_PinSocket_2.00mm:PinSocket_2x05_P2.00mm_Vertical |  |  |  |  | $0.0000 | $0.00 | 2x5 2.00 mm socket, hand-soldered (AliExpress/Farnell) | n/a
Totals per board | 63 |  |  |  |  |  |  |  | $16.63
Extended-part lines (one-off fee each per order) | 18
Lines with no JLC code (hand-soldered) | 2
Lines below thin-stock threshold | 3
Lines short for the planned run | 0

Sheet: Vision
BugBot Vision Board BOM (per board). Refs and quantities from Vision_sch_netlist.xml; prices and stock via the Parts sheet.
Refs | Qty | Value | Footprint | LCSC | MPN | Class | Stock | Unit price (USD) | Line cost (USD) | Source / status | Stock status | Datasheet
C1 | 1 | 22u | Capacitor_SMD:C_0805_2012Metric | C45783 | CL21A226MAQNNNE | Basic | 5276598 | $0.2492 | $0.25 | JLC assembly | OK | https://jlcpcb.com/partdetail/C45783
C2, C20, C43, C54 | 4 | 10u | Capacitor_SMD:C_0805_2012Metric | C15850 | CL21A106KAYNNNE | Basic | 7849987 | $0.0847 | $0.34 | JLC assembly | OK | https://jlcpcb.com/partdetail/C15850
C6, C21, C42, C44, C55 | 5 | 100n | Capacitor_SMD:C_0402_1005Metric | C1525 | CL05B104KO5NNNC | Basic | 37375769 | $0.0051 | $0.03 | JLC assembly | OK | https://jlcpcb.com/partdetail/C1525
C14 | 1 | 1u | Capacitor_SMD:C_0402_1005Metric | C52923 | CL05A105KA5NQNC | Basic | 10724896 | $0.0121 | $0.01 | JLC assembly | OK | https://jlcpcb.com/partdetail/C52923
J3 | 1 | Camera FPC 22P 0.5mm top-contact OV5647 spy (pin k = Pi Zero pin 23-k) | jlc:FPC-SMD_22P-P0.50_HDGC_0.5K-AS-22PWB | C2911765 | 0.5K-AS-22PWB | Extended | 473 | $0.1355 | $0.14 | JLC assembly | Thin | https://jlcpcb.com/partdetail/C2911765
J7 | 1 | ToF GH1.25 6P side-entry (underside) | Connector_JST:JST_GH_SM06B-GHS-TB_1x06-1MP_P1.25mm_Horizontal | C3029381 | WAFER-GH1.25-6PWB | Extended | 32531 | $0.1605 | $0.16 | JLC assembly | OK | https://jlcpcb.com/partdetail/C3029381
J10 | 1 | LED GH1.25 3P (WS2812 in the ball) | jlc:CONN-SMD_3P-P1.25_XUNPU_WAFER-GH1.25-3PLB | C3029369 | WAFER-GH1.25-3PLB | Extended | 15257 | $0.1467 | $0.15 | JLC assembly | OK | https://jlcpcb.com/partdetail/C3029369
R7, R8, R9, R14 | 4 | 10k | Resistor_SMD:R_0402_1005Metric | C25744 | 0402WGF1002TCE | Basic | 30863902 | $0.0031 | $0.01 | JLC assembly | OK | https://jlcpcb.com/partdetail/C25744
R11, R12 | 2 | 2.2k | Resistor_SMD:R_0402_1005Metric | C25879 | 0402WGF2201TCE | Basic | 1612344 | $0.0039 | $0.01 | JLC assembly | OK | https://jlcpcb.com/partdetail/C25879
R13 | 1 | 100R | Resistor_SMD:R_0402_1005Metric | C25076 | 0402WGF1000TCE | Basic | 3999877 | $0.0037 | $0.0037 | JLC assembly | OK | https://jlcpcb.com/partdetail/C25076
SW1, SW2 | 2 | ZX-QC4545-4.3TP | jlc:KEY-SMD_4P-L4.5-W4.5-P3.00-LS6.9 | C7470171 | ZX-QC4545-4.3TP | Extended | 25261 | $0.0251 | $0.05 | JLC assembly | OK | https://jlcpcb.com/partdetail/C7470171
SW3 | 1 | MSK12C02 | jlc:SW-TH_MSK12C02 | C431540 | MSK12C02 | Extended | 150031 | $0.0566 | $0.06 | JLC assembly | OK | https://jlcpcb.com/partdetail/C431540
J8 | 1 | Stack A 2x5 (mates Motion J8) | Connector_PinHeader_2.00mm:PinHeader_2x05_P2.00mm_Vertical |  |  |  |  | $0.0000 | $0.00 | 2x5 2.00 mm pin header, hand-soldered | n/a
J9 | 1 | Stack B 2x5 (mates Motion J9) | Connector_PinHeader_2.00mm:PinHeader_2x05_P2.00mm_Vertical |  |  |  |  | $0.0000 | $0.00 | 2x5 2.00 mm pin header, hand-soldered | n/a
U3 | 1 | ESP32-P4-Module | jlc:ESP32-P4-Module |  |  |  |  | $0.0000 | $0.00 | ESP32-P4 + C6 core module (Waveshare), hand-soldered | n/a | https://www.waveshare.com/wiki/ESP32-P4-Module
Totals per board | 27 |  |  |  |  |  |  |  | $1.20
Extended-part lines (one-off fee each per order) | 5
Lines with no JLC code (hand-soldered) | 3
Lines below thin-stock threshold | 1
Lines short for the planned run | 0

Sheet: Odometry
BugBot Odometry Board BOM (per board). Refs and quantities from Odometry_sch_netlist.xml; prices and stock via the Parts sheet.
Refs | Qty | Value | Footprint | LCSC | MPN | Class | Stock | Unit price (USD) | Line cost (USD) | Source / status | Stock status | Datasheet
C1, C2, C3, C4, C9 | 5 | 1u | Capacitor_SMD:C_0402_1005Metric | C52923 | CL05A105KA5NQNC | Basic | 10724896 | $0.0121 | $0.06 | JLC assembly | OK | https://jlcpcb.com/partdetail/C52923
C5 | 1 | 4.7u | Capacitor_SMD:C_0603_1608Metric | C19666 | CL10A475KO8NNNC | Basic | 4016851 | $0.0333 | $0.03 | JLC assembly | OK | https://jlcpcb.com/partdetail/C19666
C6, C7, C8 | 3 | 100n | Capacitor_SMD:C_0402_1005Metric | C1525 | CL05B104KO5NNNC | Basic | 37375769 | $0.0051 | $0.02 | JLC assembly | OK | https://jlcpcb.com/partdetail/C1525
C10, C11 | 2 | 22p | Capacitor_SMD:C_0603_1608Metric | C1653 | CL10C220JB8NNNC | Basic | 2640152 | $0.0068 | $0.01 | JLC assembly | OK | https://jlcpcb.com/partdetail/C1653
J1 | 1 | Odometry GH10 to Motion J7 | Connector_JST:JST_GH_BM10B-GHS-TBT_1x10-1MP_P1.25mm_Vertical | C3029376 | WAFER-GH1.25-10PLB | Extended | 1796 | $0.2164 | $0.22 | JLC assembly | Thin | https://jlcpcb.com/partdetail/C3029376
R1 | 1 | 47k | Resistor_SMD:R_0402_1005Metric | C25792 | 0402WGF4702TCE | Basic | 6406298 | $0.0029 | $0.0029 | JLC assembly | OK | https://jlcpcb.com/partdetail/C25792
R2 | 1 | 33k | Resistor_SMD:R_0402_1005Metric | C25779 | 0402WGF3302TCE | Basic | 1512746 | $0.0092 | $0.01 | JLC assembly | OK | https://jlcpcb.com/partdetail/C25779
R3 | 1 | 33R | Resistor_SMD:R_0402_1005Metric | C25105 | 0402WGF330JTCE | Basic | 2403330 | $0.0041 | $0.0041 | JLC assembly | OK | https://jlcpcb.com/partdetail/C25105
R4, R5, R6, R7 | 4 | 10k | Resistor_SMD:R_0402_1005Metric | C25744 | 0402WGF1002TCE | Basic | 30863902 | $0.0031 | $0.01 | JLC assembly | OK | https://jlcpcb.com/partdetail/C25744
U1 | 1 | AP2127K-ADJ | jlc:SOT-23-5_L3.0-W1.7-P0.95-LS2.8-BR | C96343 | AP2127K-ADJTRG1 | Extended | 50060 | $0.1269 | $0.13 | JLC assembly | OK | https://www.diodes.com/assets/Datasheets/AP2127.pdf
U3 | 1 | BNO055 | jlc:LGA-28_L5.2-W3.8-P0.50-BL | C93216 | BNO055 | Extended | 8957 | $9.3239 | $9.32 | JLC assembly | OK | https://www.bosch-sensortec.com/media/boschsensortec/downloads/datasheets/bst-bno055-ds000.pdf
Y1 | 1 | 32.768k | jlc:FC-135R_L3.2-W1.5 | C32346 | Q13FC13500004 | Basic | 761776 | $0.1714 | $0.17 | JLC assembly | OK | https://jlcpcb.com/partdetail/C32346
U2 | 1 | PMW3360DM-T2QU | jlc:PMW3360DM-T2QU_16Pin |  |  |  |  | $0.0000 | $0.00 | PMW3360DM-T2QU + LM19-LSI lens (Tindie/AliExpress), hand-soldered | n/a | https://www.trackballs.eu/media/Ploopy/Adept/PMW3360DM-T2QU.pdf
Totals per board | 23 |  |  |  |  |  |  |  | $9.99
Extended-part lines (one-off fee each per order) | 3
Lines with no JLC code (hand-soldered) | 1
Lines below thin-stock threshold | 1
Lines short for the planned run | 0
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

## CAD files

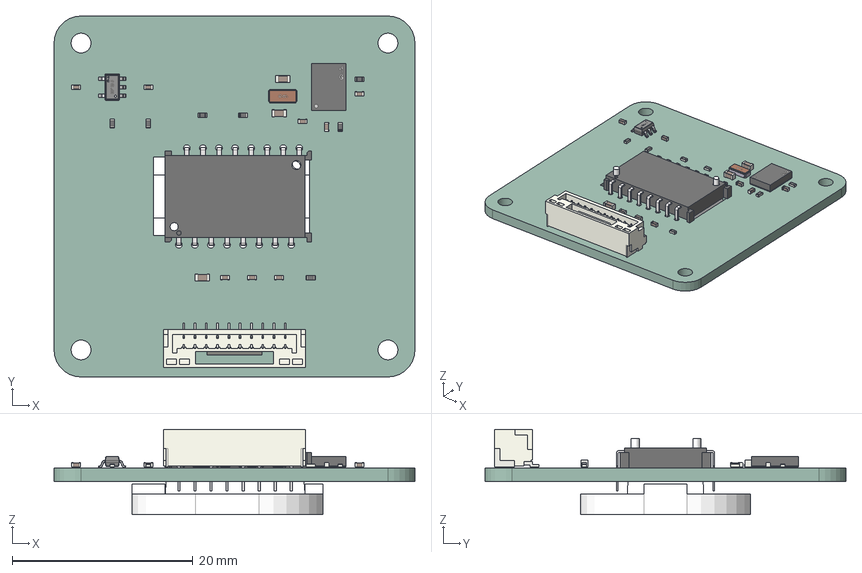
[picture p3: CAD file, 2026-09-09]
design/3d/BugBot_Odometry_Board.step
40.0 x 40.0 x 9.46 mm
C_0402_1005Metric x 8
LGA-28_L5.2-W3.8-H1.2-P0.50-BL
R_0402_1005Metric x 7
C_0603_1608Metric x 3
JST_BM10B_GHS_TBT
SOT-23-5_L2.9-W1.6-H1.1-LS2.8-P0.95
FC-135R_L3.2-W1.5
Lead x 8
Lead(Mirror) x 8
Lens
BugBot_Odometry_Board_PCB

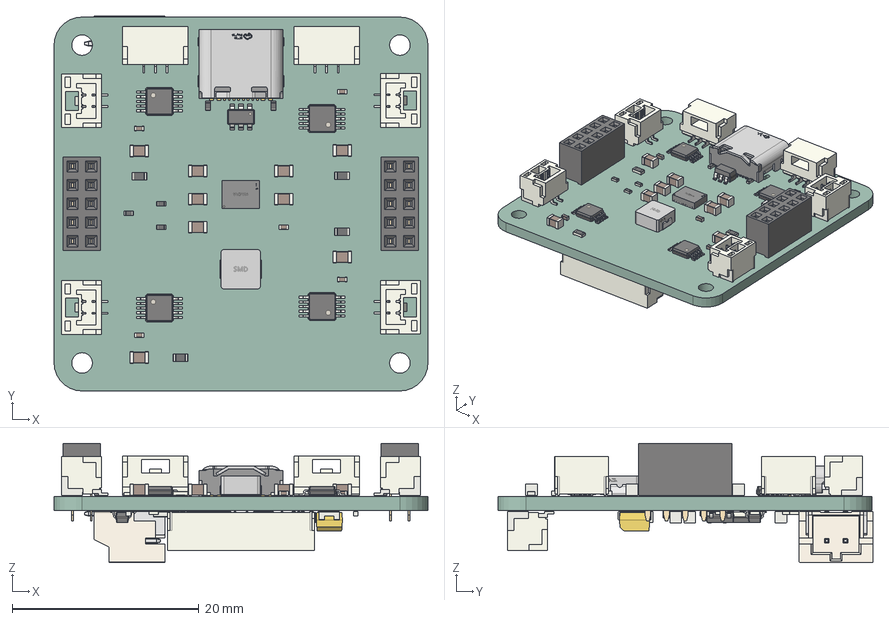
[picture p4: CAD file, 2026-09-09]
design/3d/BugBot_Motion_Board.step
40.0 x 40.1 x 12.8 mm
MSOP-10-1EP_3x3mm_P0.5mm_EP1.68x1.88mm x 4
C_0805_2012Metric x 13
JST_BM02B_GHS_TBT x 4
C_0402_1005Metric x 7
R_0402_1005Metric x 14
SOT-23-6
R_0603_1608Metric x 4
IND-SMD_L4.2-W4.4-H2.0
PinSocket_2x05_P2.00mm_Vertical x 2
VSON-14_L4.0-W3.0-H1.0-P0.50
JST_SM03B_GHS_TB x 2
USB-C-SMD_TYPE-C-6PIN-2MD-073
SOT-23 x 3
QFN-16_L3.0-W3.0-P0.50-TL-EP1.7-2
R_1812_4532Metric
JST_BM10B_GHS_TBT
L_1008_2520Metric
CP_EIA_3528_21_Kemet_B
CONN-SMD_P2.00_S2B-PH-SM4-TB-LF-SN
BugBot_Motion_Board_PCB

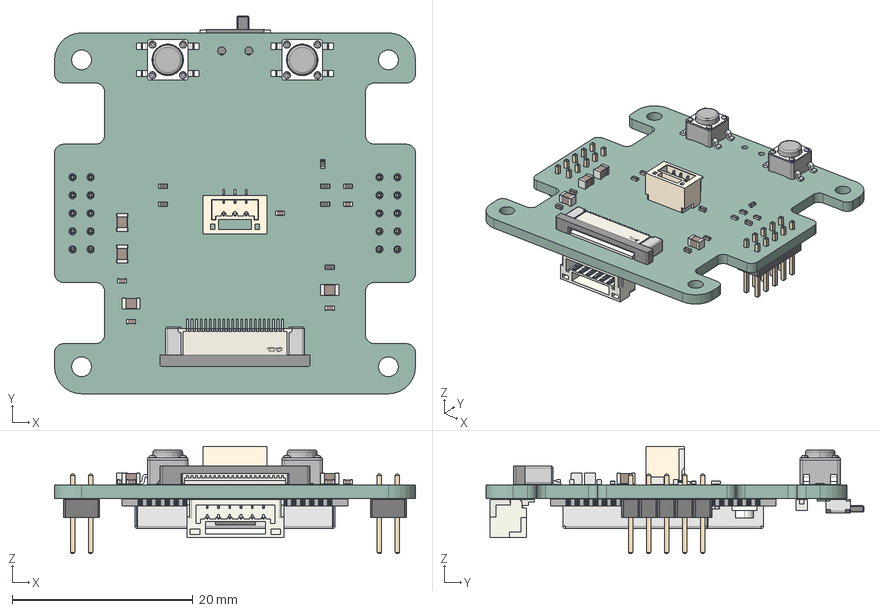
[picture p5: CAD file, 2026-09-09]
design/3d/BugBot_Vision_Board.step
40.0 x 41.8 x 11.9 mm
C_0805_2012Metric x 5
R_0402_1005Metric x 7
FPC-SMD_22P-P0.50_HDGC_0.5K-AS-22PWB
CONN-SMD_3P-P1.25_XUNPU_WAFER-GH1.25-3PLB
C_0402_1005Metric x 6
KEY-SMD_4P-L4.5-W4.5-P3.00-LS6.9 x 2
JST_SM06B_GHS_TB
SW-SMD_3P-L6.6-W2.7-LS7.8-P1.50
PinHeader_2x05_P200mm_Vertical x 2
BOARD
USER_LIBRARY-RES_0603-0201_1 x 26
USER_LIBRARY-RES_0603-0201_2 x 26
USER_LIBRARY-RES_0603-0201_3 x 26
USER_LIBRARY-RES_0603-0201_4 x 26
USER_LIBRARY-0201_0603M__CAP_1 x 42
USER_LIBRARY-0201_0603M__CAP_2 x 42
USER_LIBRARY-0201_0603M__CAP_3 x 42
L0201_1
L0201_2
L0201_3
EXTRUDED-85053
EXTRUDED-85448 x 2
EXTRUDED-85871
EXTRUDED-86290 x 6
EXTRUDED-86687
EXTRUDED-87530
3_1_A x 11
EXTRUDED-125575
ESP32-P4-MODULE000
ANT
BugBot_Vision_Board_PCB

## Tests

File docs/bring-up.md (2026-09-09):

# BugBot stack: firmware notes from the hardware design

Written 2026-09-09 from the schematic review, the ngspice harness and the pre-order audit. These are things the
firmware must do, or must know, because of how the boards are built. Pin names are the ESP32-P4 module GPIOs.

## Rules the firmware must implement

1. **Low-battery cut-off at 3.2 V.** The DRV8830 motor drivers switch off below 2.75 V on the motor rail, which
   the cell reaches at about 3.0 V under load. The 3.3 V converter keeps the P4 alive down to a 2.8 V cell, so the
   robot would keep thinking while the motors stutter and stop. Read VBAT_SENSE (GPIO20, ADC1_CH4; it is
   VSYS_SW / 2 through 100k/100k, so multiply by 2) and stop driving at 3.2 V, warn at 3.4 V. With USB present the
   reading is the charger's SYS output (up to 4.5 V), not the cell.
2. **No hard reversal without a battery.** When running from USB with the cell removed, a fast full-speed reversal
   pushes motor energy back into the motor rail and only the capacitors absorb it; the rail can exceed the drivers'
   7 V limit. Detect "no cell" (VBAT_SENSE tracks the USB-derived SYS, about 4.3 V, and the charger reports no
   battery) and always coast to a stop before reversing in that state. With a cell fitted, reversals are fine.
3. **USB charging while driving needs a 1.5 A or 2 A source.** The charger is set to 0.8 A by a resistor; driving
   adds 0.5 to 1 A, so the USB draw is 1.4 to 1.8 A. On a 0.5 A port the charger folds the charge current back
   (no damage, slow or no charging). Firmware cannot change the charge current on this board; it can only tell the
   user: if VBUS sags below 4.5 V while charging, report "weak USB supply".
4. **Charging only when cool.** The charger's thermistor RT1 sits on the Motion board near the charger and reads
   about 73 C when driving; the charger stops charging above roughly 40 C at that pin and resumes when cool. Expect
   no charging during or just after a drive; don't treat it as a fault.
5. **Motor fault line.** MOT_INT (GPIO on the stack, active low, 10k pull-up) is the wired-OR nFAULT of the four
   DRV8830s. A stalled motor trips the driver's current limit at 400 mA (0R5 sense resistor) and, after about
   275 ms at the limit, the driver latches a fault and pulls MOT_INT low. Clear it by writing IN1=IN2=0 to that
   driver. Read each driver's FAULT register to find which one.
6. **ToF module LPn.** VL53L5CX LPn is GPIO2 with no pull-up; drive it high before any I2C traffic to the module.
   INT is GPIO3.
7. **Camera enable.** CAM_EN is GPIO23 through 100R, wired to both Pi Zero flex pins 17 and 18. Drive it high to
   power the module's regulators before I2C. The OV5647 is at I2C address 0x36 on the camera's own SCL/SDA lines
   (flex pins 20/21), not the main bus.
8. **I2C speed.** One 2.2k pull-up pair on Vision serves the P4, four DRV8830s on Motion, the ToF module, the
   BNO055 over the cable and the camera. Simulated rise 244 ns (limit 300 ns at 400 kHz), so 400 kHz works but
   is marginal; use 100 kHz unless there is a reason not to.

## Addresses and pins

| Device | Bus / pins | Address |
|---|---|---|
| DRV8830 U6 / U7 / U8 / U9 (Motion) | I2C GPIO26 (SDA) / GPIO27 (SCL) | 0x60 / 0x61 / 0x62 / 0x64 |
| BNO055 IMU (Odometry, over the cable) | same I2C | 0x28 |
| VL53L5CX ToF (module on J7) | same I2C, LPn GPIO2, INT GPIO3 | 0x29 |
| OV5647 camera | camera flex SCL/SDA, CAM_EN GPIO23 | 0x36 |
| PMW3360 optical flow (Odometry) | SPI: SCLK GPIO10, MOSI GPIO11, MISO GPIO12, NCS GPIO9, MOTION GPIO8 | |
| Servos | GPIO4 (servo 1), GPIO5 (servo 2), 3.3 V PWM into 1S servos | |
| WS2812 LED ball | data GPIO7, powered from 3.3 V (below the LED's 3.5 V minimum; most units work) | |
| Battery sense | GPIO20 = VSYS_SW / 2 | |
| Motor fault | MOT_INT, active low | |
| Power switch | SW3 on Vision grounds SW_ON; a Motion board alone stays off | |

## Boot and flashing

- P4 boot straps: GPIO35 (BOOT button SW1, 10k up), GPIO36 10k up, GPIO34 10k down. EN has the module's own
  pull-up plus the RESET button SW2 and 1 uF. C6 IO8 10k up (boot strap), IO9 internal pull-up.
- Flashing: the Motion USB-C reaches the P4's USB 2.0 OTG (HS) pins over the stack. The ROM supports DFU and
  USB-CDC download on that port (not if secure boot or flash encryption is enabled). There is no UART console:
  the app must run TinyUSB CDC on the OTG port for a console. GPIO37/38 (UART0) and GPIO24/25 (USB-Serial/JTAG)
  are not brought out.
- The C6 (Wi-Fi) is reachable only through the P4 (ESP-Hosted); its own UART is not brought out.

## Bring-up checks before first power (hardware, not firmware)

- Camera flex: pin 1 = 3V3, pin 22 = GND, contacts facing up in J3.
- GH10 cable Motion J7 to Odometry J1 is the REVERSE type: J7 pad 1 to J1 pad 10 must be a short.
- Battery lead polarity against J2 (JST-PH leads are wired both ways by different sellers).

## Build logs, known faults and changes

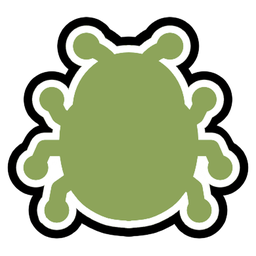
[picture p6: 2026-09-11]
viewer/assets/bug.png

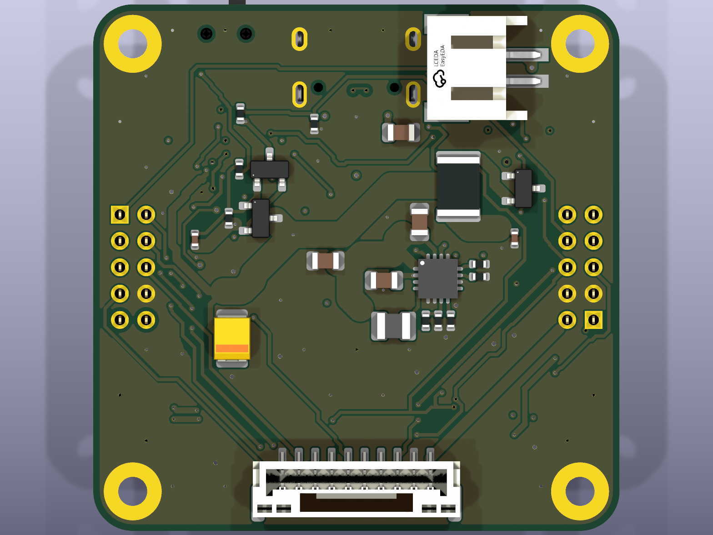
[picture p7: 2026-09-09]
design/3d/BugBot_Motion_Board_bottom.png

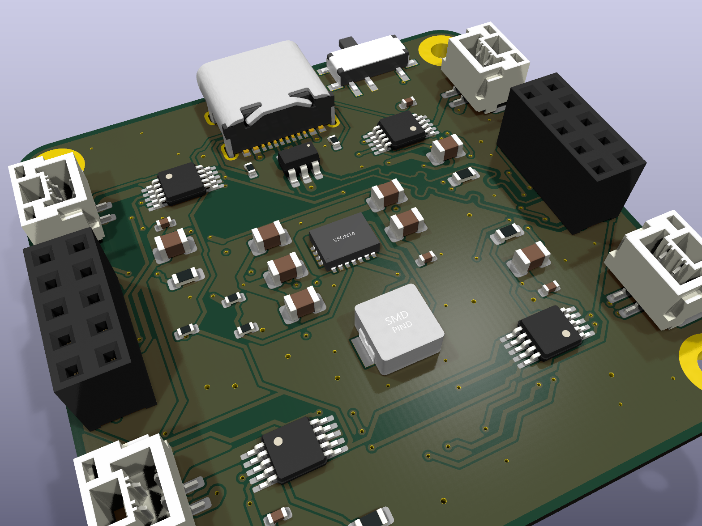
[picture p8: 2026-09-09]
design/3d/BugBot_Motion_Board_iso_top.png

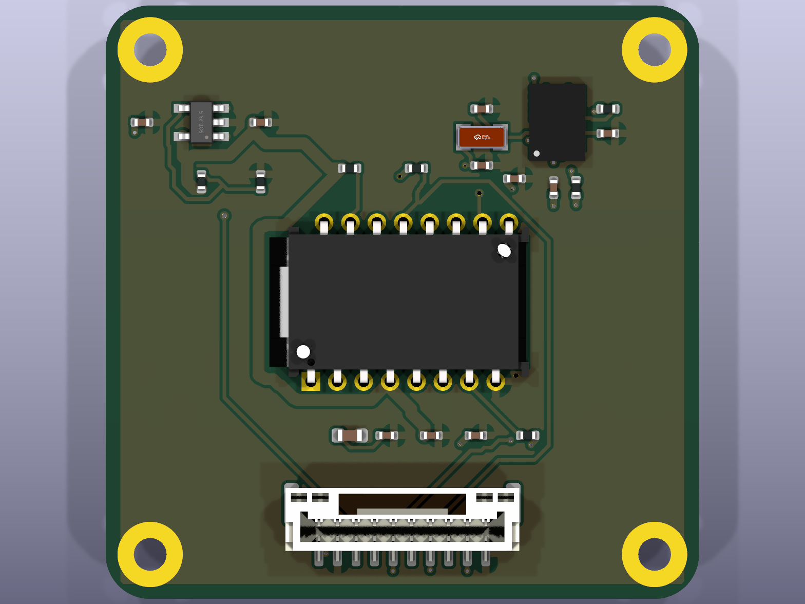
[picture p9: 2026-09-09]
design/3d/BugBot_Odometry_Board_top.png

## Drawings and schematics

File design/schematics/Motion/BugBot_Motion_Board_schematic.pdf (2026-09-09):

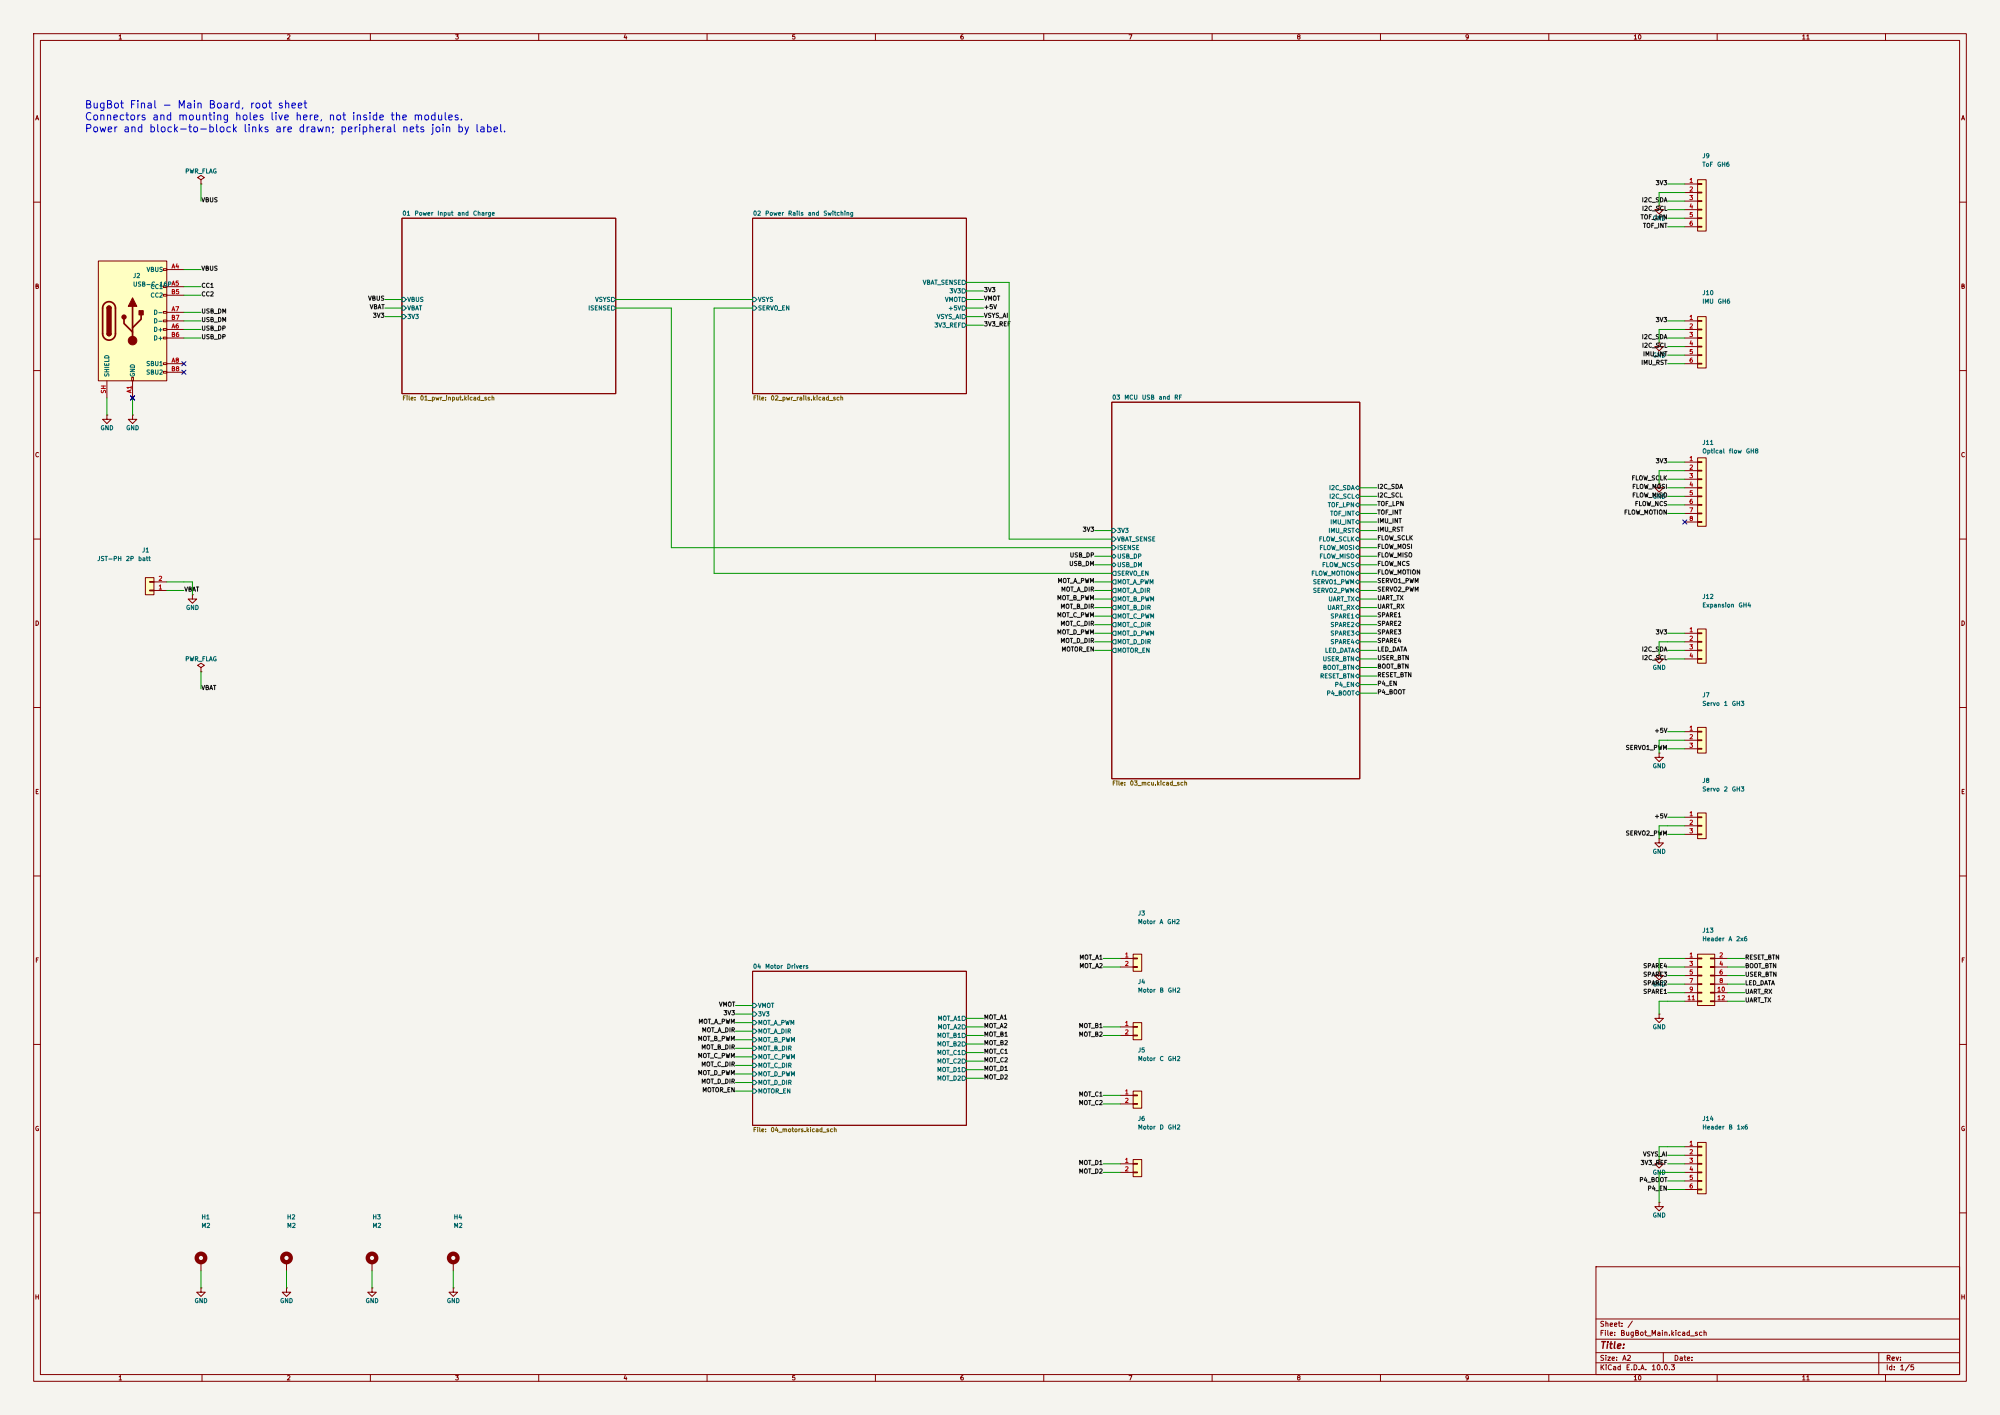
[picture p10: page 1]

Power and block-to-block links are drawn; peripheral nets join by label.

ISENSE 01 Power Input and Charge

VSYS_AI 3V3_REF 02 Power Rails and Switching

03 MCU USB and RF
MOT_A_DIR MOT_B_DIR MOT_C1

Size: A2 | Rev:
KiCad E.D.A. 10.0.3 | Id: 1/5

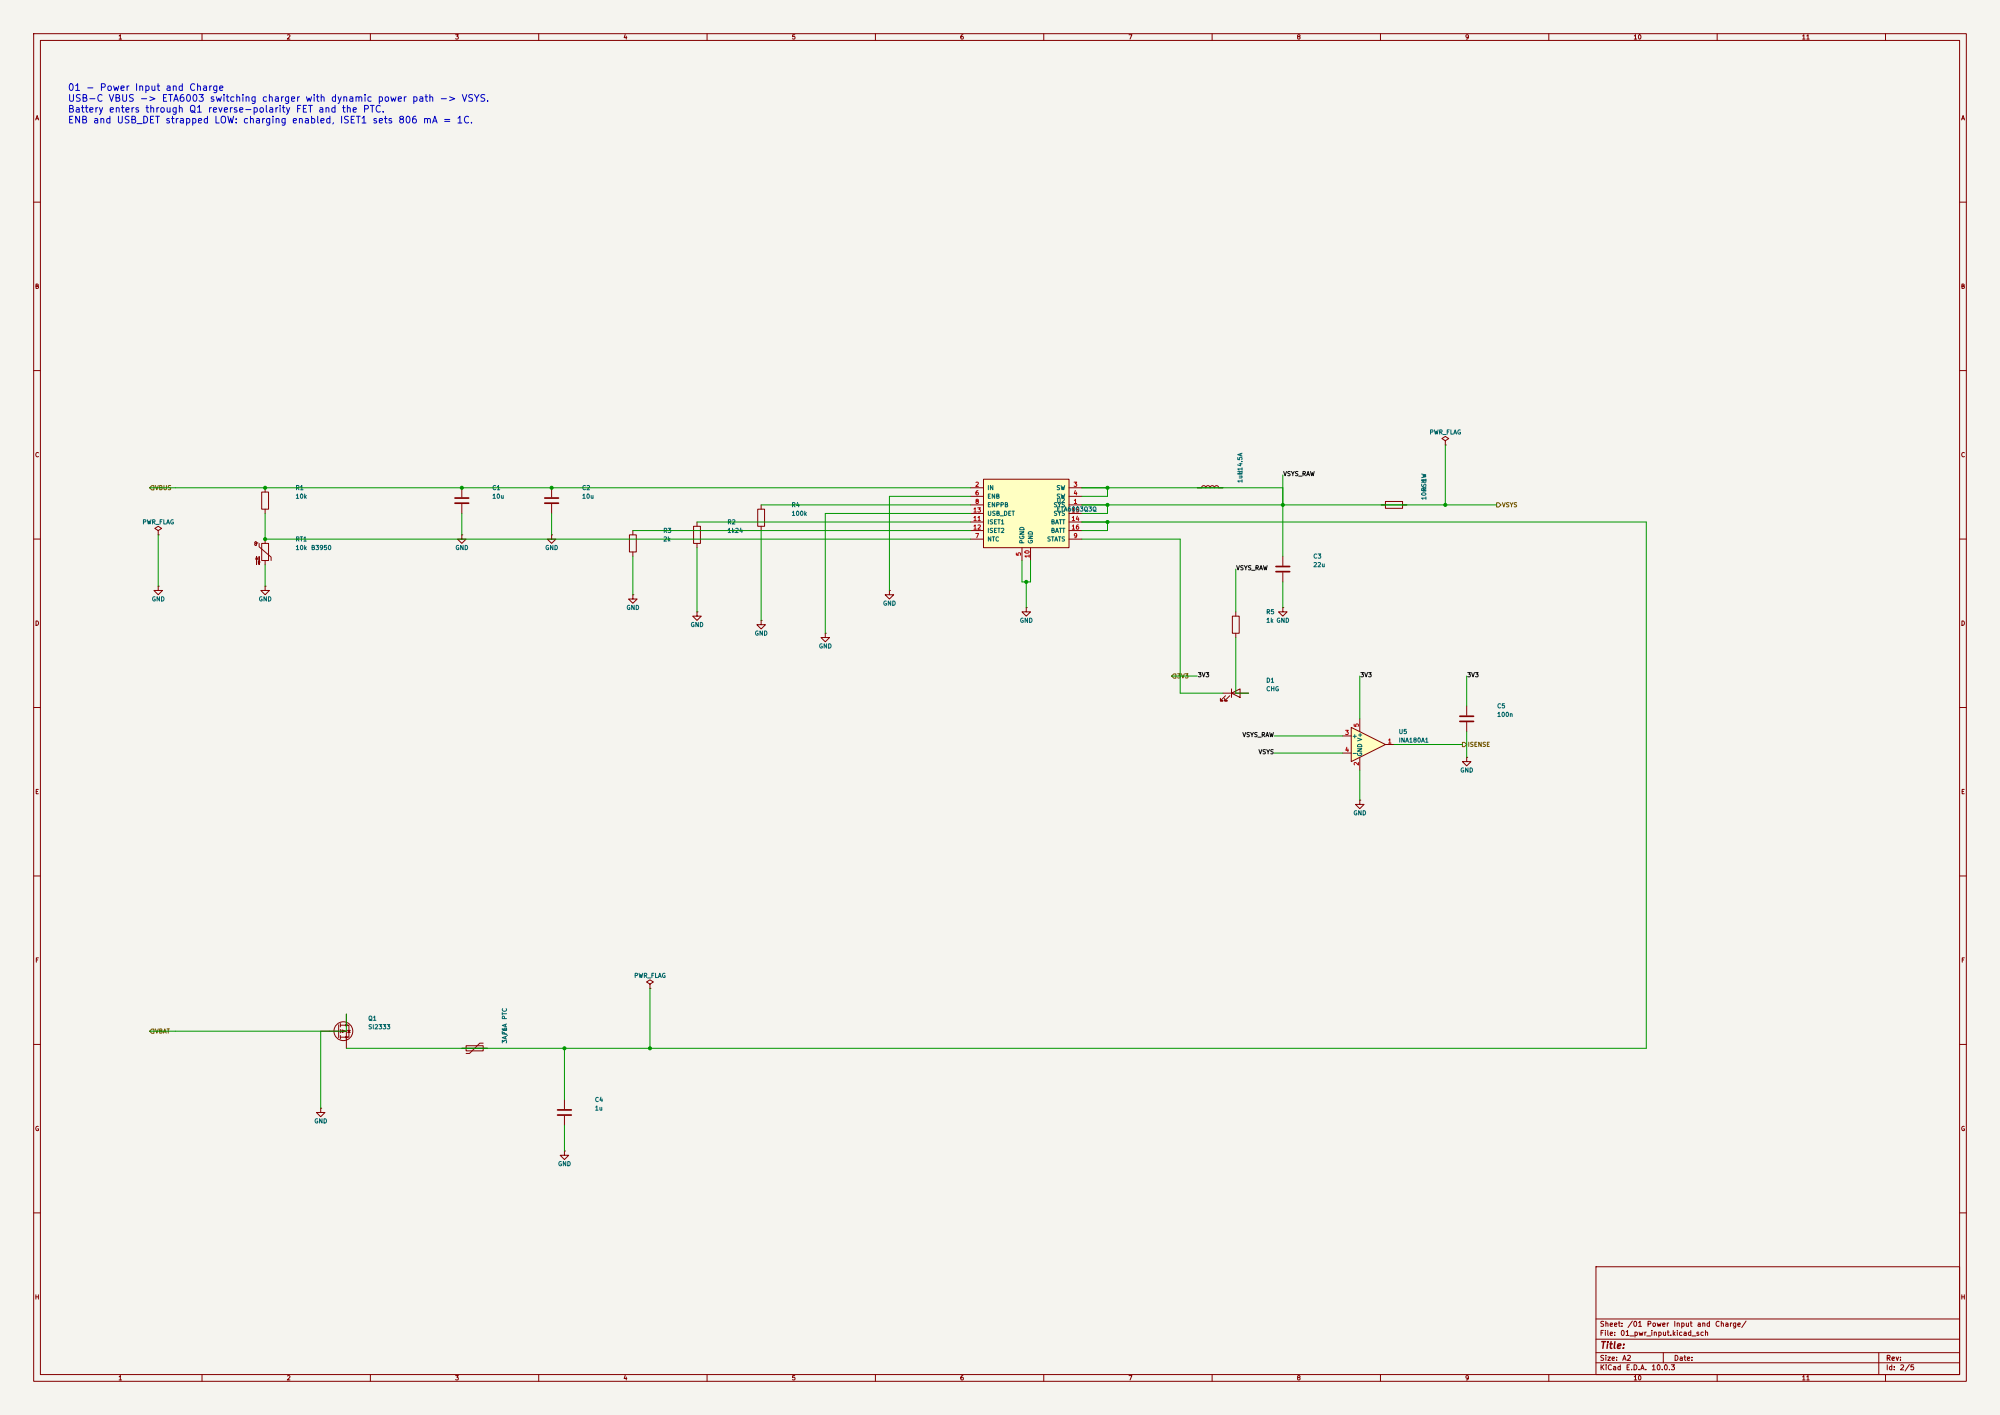
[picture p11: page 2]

01 - Power Input and Charge
USB-C VBUS -> ETA6003 switching charger with dynamic power path -> VSYS.
Battery enters through Q1 reverse-polarity FET and the PTC.

Sheet: /01 Power Input and Charge/
File: 01_pwr_input.kicad_sch

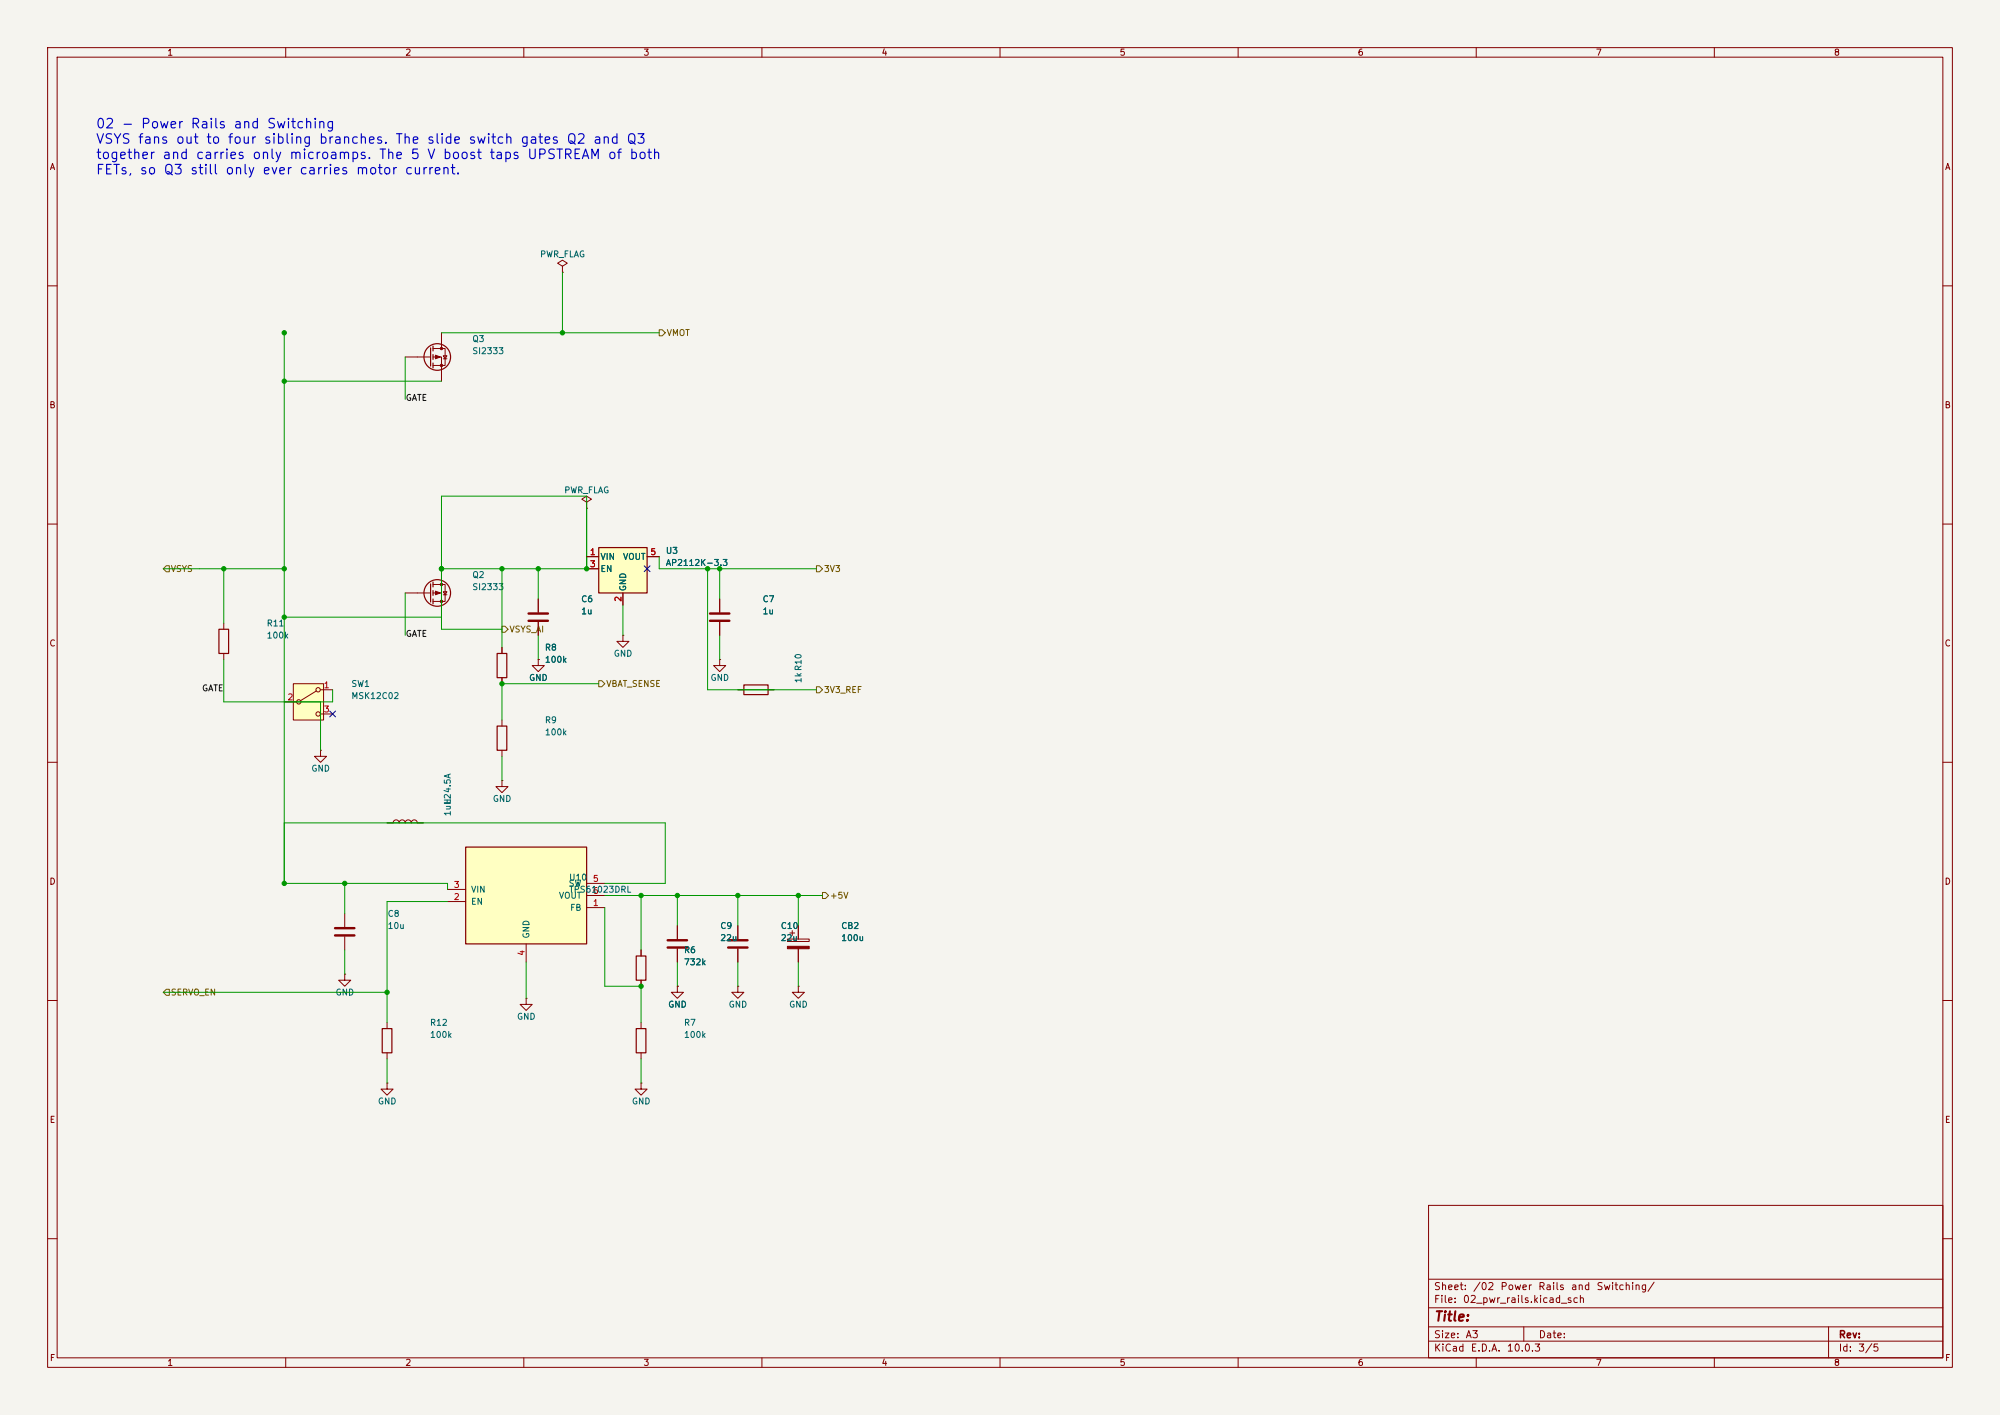
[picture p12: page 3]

VSYS fans out to four sibling branches. The slide switch gates Q2 and Q3
together and carries only microamps. The 5 V boost taps UPSTREAM of both

Sheet: /02 Power Rails and Switching/
File: 02_pwr_rails.kicad_sch

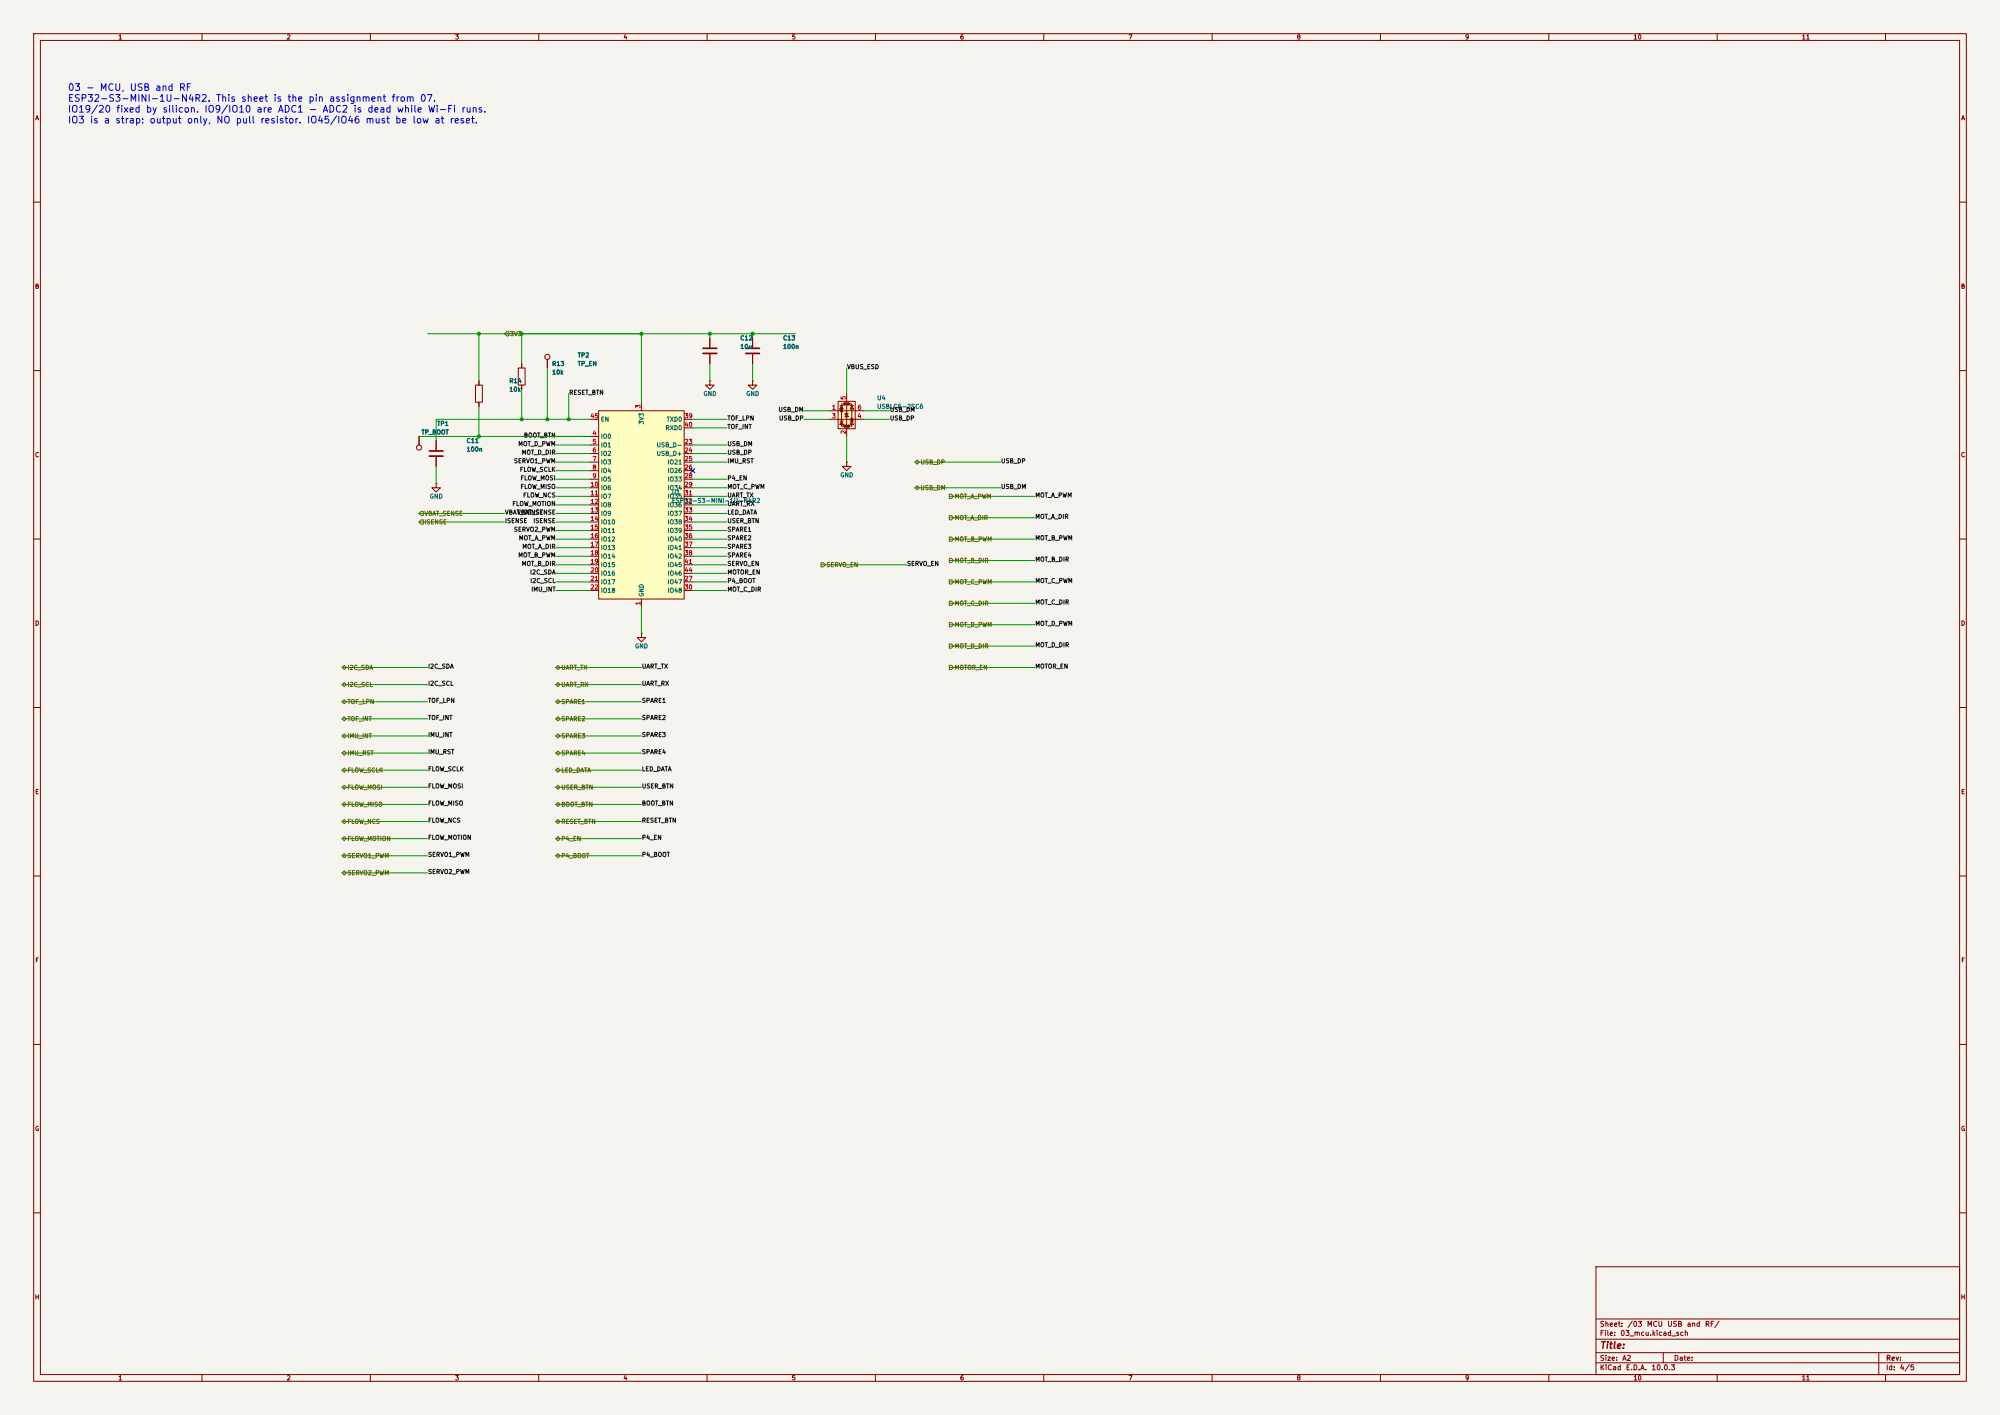
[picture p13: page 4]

ESP32-S3-MINI-1U-N4R2. This sheet is the pin assignment from 07.
IO19/20 fixed by silicon. IO9/IO10 are ADC1 - ADC2 is dead while Wi-Fi runs.

Sheet: /03 MCU USB and RF/
File: 03_mcu.kicad_sch

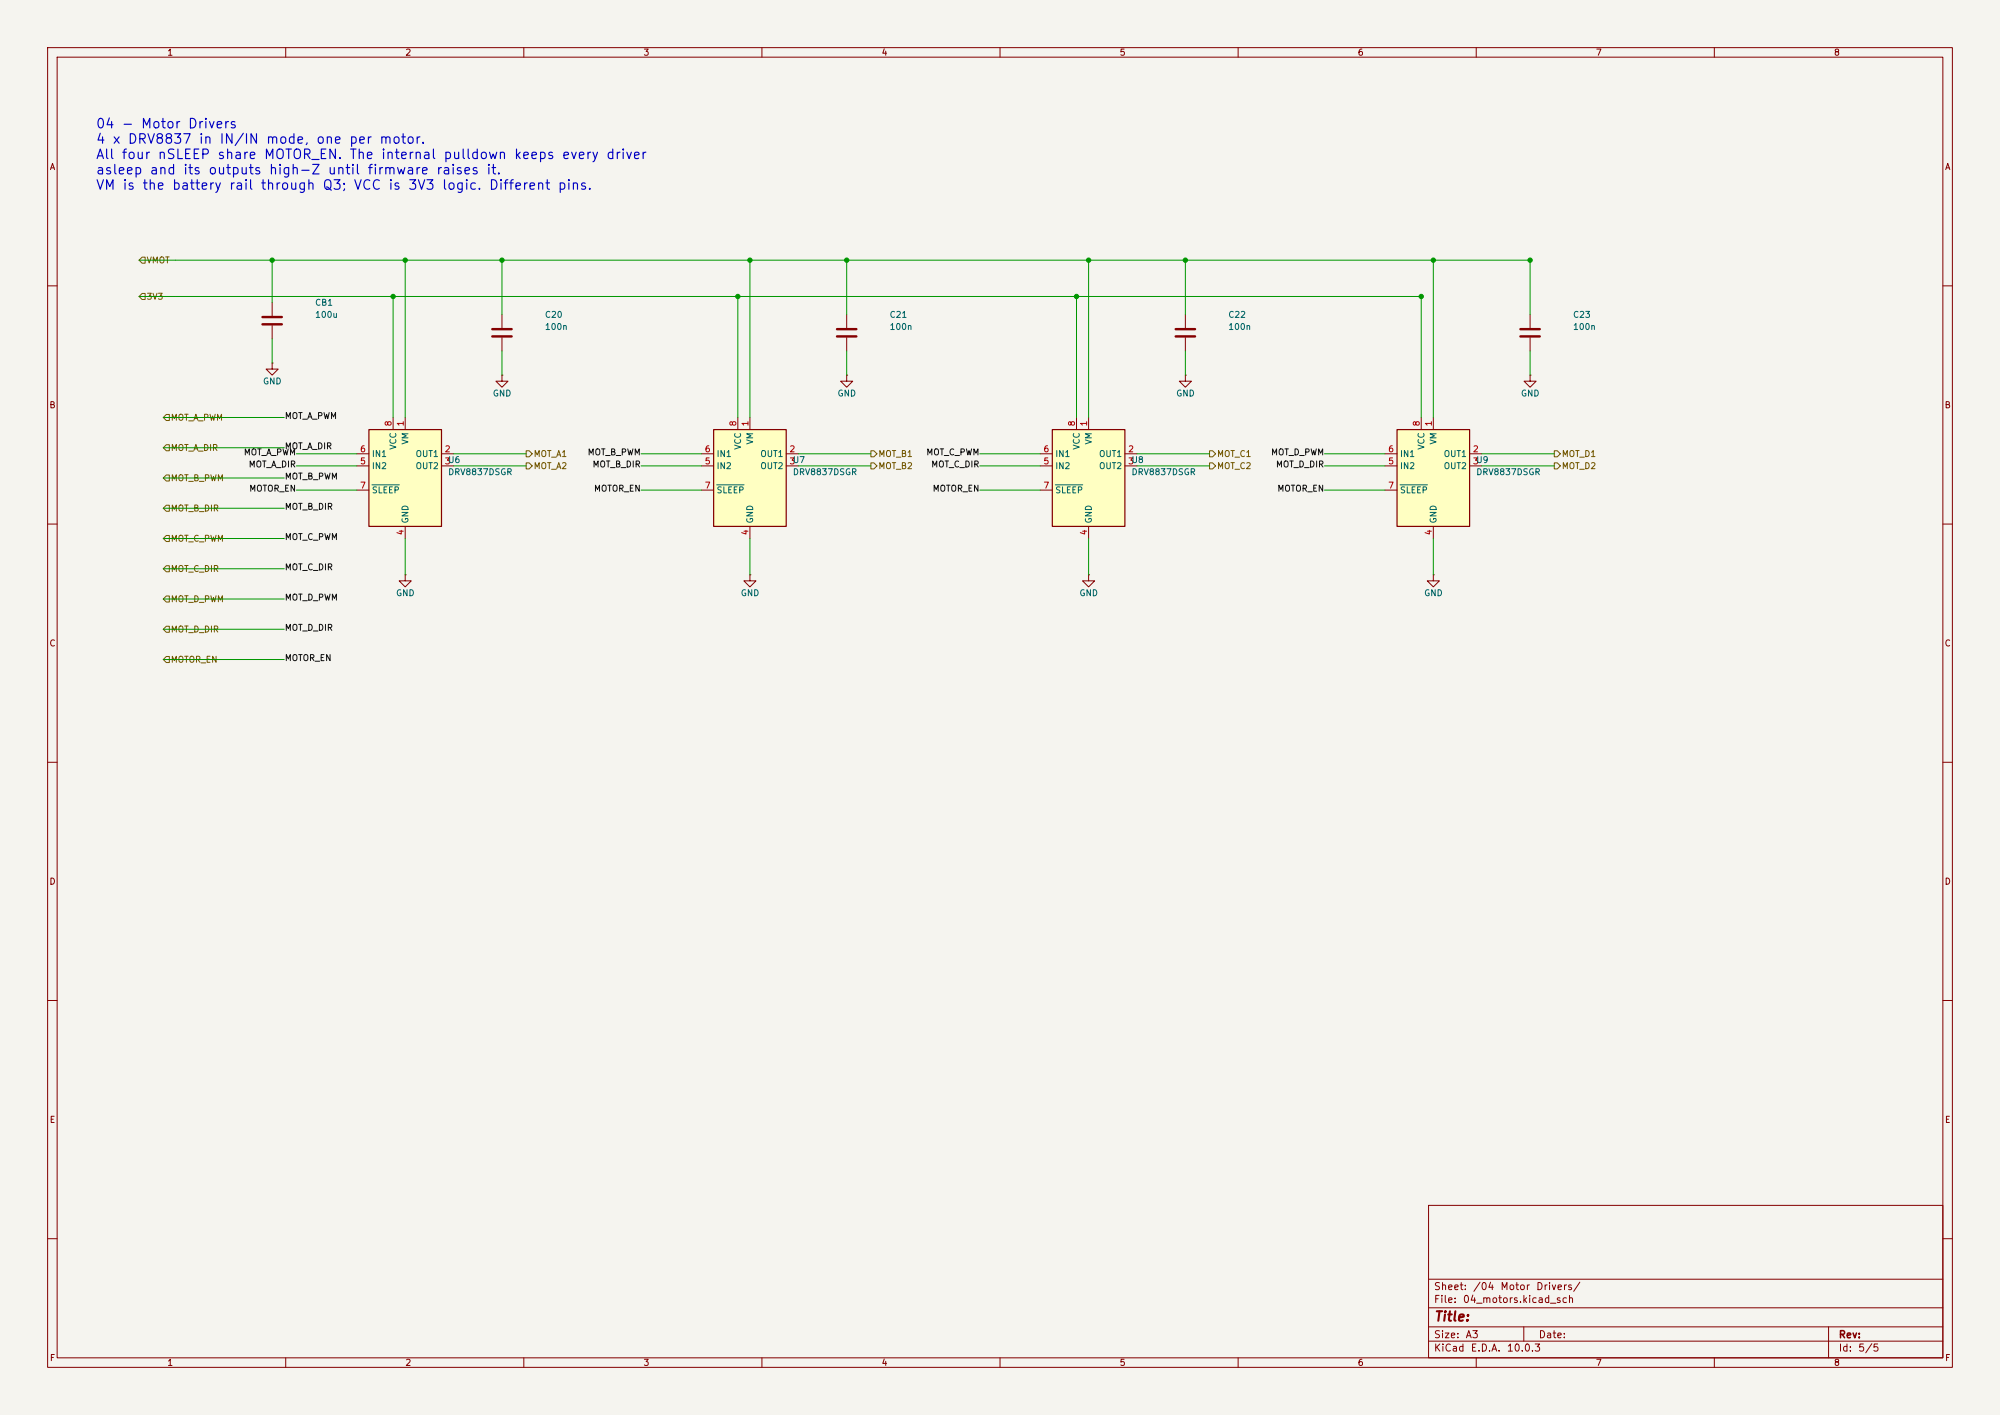
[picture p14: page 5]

MOT_D_DIR 04 - Motor Drivers
All four nSLEEP share MOTOR_EN. The internal pulldown keeps every driver
asleep and its outputs high-Z until firmware raises it.
VM is the battery rail through Q3; VCC is 3V3 logic. Different pins.

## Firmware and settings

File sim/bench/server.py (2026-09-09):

"""Interactive bench: the real schematic sheets, live from ngspice.

    python bench/server.py            ->  http://localhost:8765

The page shows every sheet of both boards (the kicad-cli SVG export) with
the wires and pins from sch_geometry.py laid over it. Click the switch, the
USB socket, the battery, a motor or the NTC and the server re-solves the
whole stack (stack_build.solve: .op, or a ramped transient when the .op
will not converge) and returns every node voltage and every element
current; the page colours the wires by voltage and animates the current.
Results are cached per state (out/bench/cache.json), so a state you have
seen before comes back instantly.
"""
import hashlib
import json
import os
import sys
import threading
from http.server import SimpleHTTPRequestHandler, ThreadingHTTPServer

HERE = os.path.dirname(os.path.abspath(__file__))
ROOT = os.path.dirname(HERE)
sys.path.insert(0, ROOT)
from paths import BOARDS, OUT, ROOT_SCH, netlist                     # noqa: E402
from stack_build import (M, V, O, NODES, MOTORS, R_ISENSE, SENSE_R,   # noqa: E402
                         motor_state, solve, stack_deck)
from ngspice_run import run_circuit, final                            # noqa: E402
from parts_spec import MOTOR_TYPES, motor_bemf                        # noqa: E402
import sch_geometry                                                   # noqa: E402

BENCH_OUT = os.path.join(OUT, "bench")
os.makedirs(BENCH_OUT, exist_ok=True)
CACHE_FILE = os.path.join(BENCH_OUT, "cache.json")
LOCK = threading.Lock()
PORT = int(sys.argv[1]) if len(sys.argv) > 1 else int(os.environ.get("PORT", "8765"))

DEFAULT_STATE = {"sw": 1, "vbus": 0.0, "vbat": 3.7, "rt1": 10000.0, "servo_a": 0.0,
                 "motor": "0615_coreless",
                 "motors": {"U6": "off", "U7": "off", "U8": "off", "U9": "off"}}

# series in out/mission_*.json -> the SPICE node each one is a voltage of
MISSION_NODES = {"VSYS": NODES["VSYS"], "VSYS_SW": NODES["VSYS_SW"], "VMOT": NODES["VMOT"],
                 "3V3": NODES["3V3_M"], "MOD_3V3": NODES["MOD_3V3"], "MOT_INT": NODES["MOT_INT_V"],
                 "GATE": NODES["GATE"], "VBAT_SENSE": NODES["VBAT_SENSE_M"]}


# --------------------------------------------------------------- geometry
def build_geometry():
    boards = {}
    for bd, pre, B in (("motion", "M", M), ("vision", "V", V), ("odometry", "O", O)):
        _, sheets = sch_geometry.load_project(netlist(bd), BOARDS[bd], ROOT_SCH[bd], pre)
        svgs = sorted(os.listdir(os.path.join(BOARDS[bd], "sheets")))
        base = ROOT_SCH[bd][:-len(".kicad_sch")]
        out = []
        for sh in sheets:
            if sh["name"] == "root":
                svg = base + ".svg"
            else:
                svg = next((s for s in svgs if s.startswith(base + "-") and s[len(base) + 1:].lower().startswith(sh["name"].lower()[:2])), None)
                if svg is None:
                    svg = next((s for s in svgs if sh["name"].split(" ", 1)[-1][:8].lower() in s.lower()), None)
            nets = sorted({w["net"] for w in sh["wires"] if w["net"]} | {p["net"] for p in sh["pins"] if p["net"]})
            out.append({"name": sh["name"], "svg": "/sheets/%s/%s" % (bd, svg) if svg else None,
                        "size": sh["size"], "wires": sh["wires"], "junctions": sh["junctions"],
                        "labels": sh["labels"], "symbols": sh["symbols"], "pins": sh["pins"],
                        "spice": {n: B.node(n).lower() for n in nets}})
        boards[bd] = {"prefix": pre, "sheets": out,
                      "values": {r: c["value"] for r, c in B.comps.items()}}
    return {"boards": boards, "motor_types": {k: {kk: vv for kk, vv in v.items() if not isinstance(vv, (list, dict))}
                                              for k, v in MOTOR_TYPES.items()},
            "default": DEFAULT_STATE, "r_isense": R_ISENSE}


GEOMETRY = None


def geometry():
    global GEOMETRY
    if GEOMETRY is None:
        GEOMETRY = build_geometry()
    return GEOMETRY


# ------------------------------------------------------------------ solve
def state_key(st):
    return hashlib.sha1(json.dumps(st, sort_keys=True).encode()).hexdigest()[:16]


def load_cache():
    try:
        return json.load(open(CACHE_FILE))
    except Exception:
        return {}


CACHE = load_cache()


def element_currents(v, B):
    """{ref: I} for every modelled element of board B, + = into pin 1 (R/C/L),
    drain current for the FETs, output current for the ICs where the model
    has a sensing source."""
    out = {}
    pre = B.prefix.lower()
    for ref in B.comps:
        tag = "%s_%s" % (pre, ref.lower())
        kind = ref.rstrip("0123456789")
        cand = []
        if kind in ("R", "RSH", "RT", "F"):
            cand = ["@r%s[i]" % tag]
        elif kind in ("C", "CB"):
            cand = ["@c%s[i]" % tag]
        elif kind == "L":
            cand = ["l%s#branch" % tag, "@l%s[i]" % tag]
        elif kind == "Q":
            cand = ["@m%s[id]" % tag]
        elif kind == "U":
            cand = ["v.x%s.vosns#branch" % tag, "v.x%s.viset#branch" % tag]
        for c in cand:
            if c in v:
                out[ref] = final(v, c)
                break
    return out


def pin_currents(v, nodes, st, ro):
    """{board: {ref: {pin: I}}}, + = current flowing INTO the pin from the
    wire, for the parts whose element current does not say it: the ICs, the
    connectors (cell, USB, motors, loads) and the J8/J9 socket links."""
    pc = {"M": {}, "V": {}, "O": {}}

    def put(b, ref, pin, i):
        pc[b].setdefault(ref, {})[pin] = i

    def vn(node):
        return nodes.get((node or "").lower(), 0.0)

    from stack_build import I_MODULE, I_CAM, I_TOF, I_LED, CAM_3V3_PIN
    from parts_spec import PARTS
    # drivers + their motors: ISENSE current, direction from the output voltages
    for sref, drv in SENSE_R.items():
        i = ro.get("I_" + drv, 0.0)
        o1, o2 = M.pin(drv, "1"), M.pin(drv, "3")
        hi, lo = ("1", "3") if vn(o1) >= vn(o2) else ("3", "1")
        put("M", drv, hi, -i); put("M", drv, lo, i); put("M", drv, "5", i); put("M", drv, "2", -i)
        jref = dict(MOTORS)[drv]
        p1, p2 = M.pin(jref, "1"), M.pin(jref, "2")
        if vn(p1) >= vn(p2):
            put("M", jref, "1", i); put("M", jref, "2", -i)
        else:
            put("M", jref, "2", i); put("M", jref, "1", -i)
    # cell and USB
    ic, iu = ro.get("I_CELL", 0.0), ro.get("I_USB", 0.0)
    for (r, p), n in M.pinnet.items():
        if r == "J2":
            put("M", "J2", p, ic if n == "GND" else -ic)
        if r == "J1" and n.endswith("VBUS"):
            put("M", "J1", p, -iu / 4)
    # charger: USB in, battery in (discharging) / out (charging), SYS out
    isw = ro.get("I_SW", 0.0)
    put("M", "U1", "2", iu)
    for p in ("14", "16"):
        put("M", "U1", p, ic / 2)
    for p in ("1", "15"):
        put("M", "U1", p, -isw / 2)
    # buck-boost: output current from the model's sense source, input by power balance
    iout = abs(final(v, "v.xm_u3.vosns#branch")) if "v.xm_u3.vosns#branch" in v else 0.0
    vin, vout = vn(M.pin("U3", "10")), vn(M.pin("U3", "4"))
    iin = iout * vout / max(vin, 0.5) / 0.9 if vout > 0.5 else 0.0
    for p in ("4", "5"):
        put("M", "U3", p, -iout / 2)
    for p in ("10", "11"):
        put("M", "U3", p, iin / 2)
    # socket links: R_J8_k from the Motion pin to the Vision pin
    for j in ("J8", "J9"):
        for k in range(1, 11):
            vec = "@r_%s_%d[i]" % (j.lower(), k)
            if vec in v:
                i = final(v, vec)
                put("M", j, str(k), i); put("V", j, str(k), -i)
    # the J7 cable: R_J7_k from the Motion pin to the Odometry J1 pin
    for k in range(1, 11):
        vec = "@r_j7_%d[i]" % k
        if vec in v:
            i = final(v, vec)
            put("M", "J7", str(k), i); put("O", "J1", str(11 - k), -i)   # mirrored connector (2026-09-07)
    # the Odometry board's own parts: the LDO from its sense source, the two
    # sensors from their modelled currents once their rails are up
    ildo = abs(final(v, "v.xo_u1.vsns#branch")) if "v.xo_u1.vsns#branch" in v else 0.0
    put("O", "U1", "1", ildo + 60e-6); put("O", "U1", "5", -ildo)
    up19 = 1.0 if vn(O.pin("U2", "4")) > 1.7 else 0.0
    up33 = 1.0 if vn(O.pin("U3", "3")) > 2.3 else 0.0
    pm, bn = PARTS["PMW3360"]["model"], PARTS["BNO055"]["model"]
    put("O", "U2", "4", pm["i_run"] * up19); put("O", "U2", "15", pm["i_led"] * up19)
    put("O", "U2", "5", pm["i_vddio"] * up19); put("O", "U2", "8", -(pm["i_run"] + pm["i_led"] + pm["i_vddio"]) * up19)
    put("O", "U3", "3", bn["i_ndof"] * up33); put("O", "U3", "28", bn["i_vddio"] * up33)
    put("O", "U3", "2", -bn["i_ndof"] * up33)
    # the loads the harness hangs on the Vision board
    put("V", "U3", "85", I_MODULE); put("V", "J3", str(CAM_3V3_PIN), I_CAM); put("V", "J7", "1", I_TOF)
    put("V", "J10", "1", I_LED)
    if st.get("servo_a"):
        put("M", "J10", "2", float(st["servo_a"])); put("M", "J11", "2", float(st["servo_a"]))
    return pc


def run_state(st):
    st = dict(DEFAULT_STATE, **st)
    st["motors"] = dict(DEFAULT_STATE["motors"], **st.get("motors", {}))
    key = state_key(st)
    if key in CACHE and "pincur" in CACHE[key]:
        return CACHE[key]
    os.environ["MOTOR"] = st["motor"]
    import stack_build
    stack_build.MOTOR_TYPE = st["motor"]
    kw = dict(vbat=float(st["vbat"]), vbus=float(st["vbus"]), sw=int(st["sw"]),
              motors=motor_state(**{k: (v if v != "stall" else "stall") for k, v in st["motors"].items()}),
              servo_a=float(st["servo_a"]), rt1=float(st["rt1"]), extra=[".options savecurrents"])
    with LOCK:
        v = solve("bench", **kw)
    nodes = {k: final(v, k) for k in v if not k.startswith(("@", "_")) and "#branch" not in k and k != "time"}
    currents = {"M": element_currents(v, M), "V": element_currents(v, V), "O": element_currents(v, O)}
    # readouts
    ro = {"I_CELL": -final(v, "vbat#branch"), "I_USB": -final(v, "vbus#branch") if st["vbus"] else 0.0}
    for name, node in NODES.items():
        ro[name] = nodes.get(node.lower(), 0.0)
    ro["I_SW"] = final(v, "@s_sw1[i]") if "@s_sw1[i]" in v else 0.0
    mt = MOTOR_TYPES[st["motor"]]
    for sref, drv in SENSE_R.items():
        i = nodes.get(M.pin(sref, "1").lower(), 0.0) / R_ISENSE
        ro["I_" + drv] = i
        s = st["motors"][drv]
        vm = ro.get("VMOT", 0.0)
        # DC motors here: speed from the back-EMF the model was given (parts_spec)
        if s in ("fwd", "rev") and vm > 2.75:
            ro["RPM_" + drv] = (1 if s == "fwd" else -1) * 0.8 * mt["rpm_noload_3v"] * min(vm, 3.0) / 3.0
        else:
            ro["RPM_" + drv] = 0.0
    pc = pin_currents(v, nodes, st, ro)
    res = {"key": key, "state": st, "nodes": nodes, "currents": currents, "pincur": pc, "readouts": ro,
           "via_tran": bool(v.get("_via_tran")), "warning": run_circuit.last_warning}
    CACHE[key] = res
    try:
        json.dump(CACHE, open(CACHE_FILE, "w"))
    except Exception:
        pass
    return res


def missions():
    out = {}
    for f in sorted(os.listdir(OUT)):
        if f.startswith("mission_") and f.endswith(".json"):
            m = json.load(open(os.path.join(OUT, f)))
            m["node_of"] = {k: n.lower() for k, n in MISSION_NODES.items()}
            out[m["name"]] = m
    return out


# ------------------------------------------------------------------- http
class Handler(SimpleHTTPRequestHandler):
    def __init__(self, *a, **k):
        super().__init__(*a, directory=os.path.join(HERE, "static"), **k)

    def log_message(self, fmt, *args):
        if "/api/" in str(args[0] if args else ""):
            super().log_message(fmt, *args)

    def handle(self):
        try:
            super().handle()
        except ConnectionAbortedError:
            pass

    def _json(self, obj, code=200):
        data = json.dumps(obj).encode()
        self.send_response(code)
        self.send_header("Content-Type", "application/json")
        self.send_header("Content-Length", str(len(data)))
        self.send_header("Cache-Control", "no-store")
        self.end_headers()
        self.wfile.write(data)

    def do_GET(self):
        if self.path == "/" or self.path.startswith("/?"):
            self.path = "/index.html"
        if self.path.startswith("/sheets/"):
            bd, _, name = self.path[len("/sheets/"):].partition("/")
            from urllib.parse import unquote
            p = os.path.join(BOARDS.get(bd, ""), "sheets", unquote(name))
            if os.path.isfile(p):
                data = open(p, "rb").read()
                self.send_response(200)
                self.send_header("Content-Type", "image/svg+xml")
                self.send_header("Content-Length", str(len(data)))
                self.end_headers()
                self.wfile.write(data)
                return
            self.send_error(404)
            return
        if self.path == "/api/geometry":
            return self._json(geometry())
        if self.path == "/api/missions":
            return self._json(missions())
        return super().do_GET()

    def do_POST(self):
        n = int(self.headers.get("Content-Length", "0"))
        body = json.loads(self.rfile.read(n) or b"{}")
        if self.path == "/api/solve":
            try:
                return self._json(run_state(body))
            except Exception as e:
                import traceback
                traceback.print_exc()
                return self._json({"error": str(e)}, 500)
        self.send_error(404)


if __name__ == "__main__":
    print("building geometry ...")
    g = geometry()
    for bd, b in g["boards"].items():
        for sh in b["sheets"]:
            print("  %s %-32s %3d wires  %3d pins  svg=%s" % (bd, sh["name"], len(sh["wires"]), len(sh["pins"]), sh["svg"]))
    print("warming the default state ...")
    run_state({})
    print("bench at http://localhost:%d" % PORT)
    ThreadingHTTPServer(("127.0.0.1", PORT), Handler).serve_forever()

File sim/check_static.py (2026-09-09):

"""Static checks the simulation cannot make: pins the models do not use,
straps, address uniqueness, pull-ups, connector pairing. Read straight from
the golden netlists against the CONFIRMED datasheet pin tables in
parts_spec.PARTS[...]["pinout"].

    python check_static.py            (also run at the start of sim_stack.py)

Why: the DRV8830 pinout error (2026-09-04) passed every ngspice scenario
because the simulation and the schematic shared the same wrong pin table.
These checks tie each IC pin to what the DATASHEET says must be on it.
"""
import os
import sys

sys.path.insert(0, os.path.dirname(os.path.abspath(__file__)))
from netlist2spice import Board, parse_val
from parts_spec import PARTS
from paths import netlist

RESULTS = []


def chk(desc, ok, detail=""):
    RESULTS.append((desc, bool(ok)))
    print("   %s  %s%s" % ("PASS" if ok else "FAIL", desc, ("  [" + detail + "]") if detail else ""))
    return bool(ok)


def leaf(net):
    return (net or "").rsplit("/", 1)[-1]


def netname(B, ref, pin):
    return B.pinnet.get((ref, pin))


def is_gnd(n):
    return n == "GND"


def is_open(n):
    return n is None or n.startswith("unconnected-")


def run(M, V, O=None):
    print("\n== STATIC: netlist against the datasheet pin tables")
    ok = True
    boards = [(M, "motion"), (V, "vision")] + ([(O, "odometry")] if O is not None else [])
    # ---- symbol pin NAMES vs the datasheet pin table (pinfunction carries the symbol's pin name)
    import xml.etree.ElementTree as ET
    for B, bd in boards:
        root = ET.parse(netlist(bd)).getroot()
        fn = {}
        for n in root.iter("net"):
            for nd in n.iter("node"):
                fn[(nd.get("ref"), nd.get("pin"))] = (nd.get("pinfunction") or "").rsplit("_", 1)[0]
        for ref, meta in B.comps.items():
            part = next((k for k in PARTS if "pinout" in PARTS[k] and meta["value"].startswith(k.split("-")[0])), None)
            if not part:
                continue
            table = PARTS[part]["pinout"]
            bad = []
            for pin, name in table.items():
                got = fn.get((ref, pin))
                if got is None:
                    continue
                def canon(x):
                    x = x.split(" ")[0].lower().replace("~{", "").replace("}", "").replace("/", "")
                    return {"nfault": "fault", "faultn": "fault", "stats": "stat", "pssync": "pssync",
                            "shdn": "en", "shutdown": "en", "ncadj": "adj",
                            "nboot_load_pin": "boot_load_pin", "nreset": "reset", "ncs": "cs"}.get(x, x)
                want, g2 = canon(name), canon(got)
                if want != g2 and not (want == "ep" or g2 == "ep" or want.startswith("gnd") and g2.startswith("gnd")):
                    bad.append("%s: datasheet %s, symbol %s" % (pin, name, got))
            ok &= chk("%s.%s %s symbol pin names match the datasheet table" % (B.prefix, ref, part), not bad, "; ".join(bad))

    # ---- DRV8830 (SLVSAB2F): straps, bus, supply
    addr = {("0", "0"): 0x60, ("0", "Z"): 0x61, ("0", "1"): 0x62, ("Z", "0"): 0x63, ("Z", "Z"): 0x64,
            ("Z", "1"): 0x65, ("1", "0"): 0x66, ("1", "Z"): 0x67, ("1", "1"): 0x68}
    seen = {}
    for ref in sorted(r for r, m in M.comps.items() if m["value"].startswith("DRV8830")):
        vcc, gnd, pad = netname(M, ref, "4"), netname(M, ref, "5"), netname(M, ref, "11")
        ok &= chk("%s pin 4 VCC on the motor rail, pin 5 GND and pad on GND" % ref,
                  leaf(vcc) == "VMOT" and is_gnd(gnd) and is_gnd(pad), "4=%s 5=%s 11=%s" % (leaf(vcc), gnd, pad))
        sda, scl = netname(M, ref, "9"), netname(M, ref, "10")
        ok &= chk("%s pin 9 SDA / pin 10 SCL on the I2C bus" % ref, leaf(sda) == "I2C_SDA" and leaf(scl) == "I2C_SCL",
                  "9=%s 10=%s" % (leaf(sda), leaf(scl)))

        def level(n):
            return "0" if is_gnd(n) else "Z" if is_open(n) else "1" if leaf(n) in ("VMOT", "VCC", "3V3", "VSYS") else "?"
        a0, a1 = level(netname(M, ref, "7")), level(netname(M, ref, "8"))
        a = addr.get((a1, a0))
        ok &= chk("%s address straps A1=%s A0=%s -> 0x%02X" % (ref, a1, a0, a or 0), a is not None and a not in seen.values(),
                  "duplicate of %s" % seen.get(a, "") if a in seen.values() else "")
        seen[ref] = a
        isn = netname(M, ref, "2")
        rs = [r for (r, p), n in M.pinnet.items() if n == isn and r.startswith("R")]
        rv = parse_val(M.comps[rs[0]]["value"]) if rs else None
        ok &= chk("%s ISENSE resistor %s = %s ohm -> limit %.0f mA (R <= 1 ohm)" % (ref, rs[0] if rs else "?", rv, 0.2 / rv * 1e3 if rv else 0),
                  rv is not None and rv <= 1.0)
        flt = netname(M, ref, "6")
        ok &= chk("%s FAULTn on MOT_INT" % ref, leaf(flt) == "MOT_INT", leaf(flt))
    pulls = [r for (r, p), n in M.pinnet.items() if leaf(n) == "MOT_INT" and r.startswith("R")]
    ok &= chk("MOT_INT has a pull-up (open-drain wire-OR)", bool(pulls), ",".join(pulls))

    # ---- TPS63020 (SLVS916I)
    u3 = next(r for r, m in M.comps.items() if m["value"].startswith("TPS63020"))
    vin = {netname(M, u3, p) for p in ("10", "11")}
    ok &= chk("U3 VIN pins 10/11 on one net, VINA 1 and EN 12 fed from it", len(vin) == 1 and netname(M, u3, "1") in vin and netname(M, u3, "12") in vin)
    ps = netname(M, u3, "13")
    ok &= chk("U3 PS/SYNC 13 tied (must not float): %s" % ("high = forced PWM" if ps in vin else "GND = power save" if is_gnd(ps) else "FLOATING"), not is_open(ps))
    ok &= chk("U3 VOUT pins 4/5 on 3V3", {leaf(netname(M, u3, "4")), leaf(netname(M, u3, "5"))} == {"3V3"})
    fb = netname(M, u3, "3")
    fbr = [r for (r, p), n in M.pinnet.items() if n == fb and r.startswith("R")]
    if len(fbr) == 2:
        vals = {r: parse_val(M.comps[r]["value"]) for r in fbr}
        top = [r for r in fbr if leaf(M.pinnet[(r, "1")]) == "3V3" or leaf(M.pinnet[(r, "2")]) == "3V3"]
        bot = [r for r in fbr if r not in top]
        vout = 0.5 * (1 + vals[top[0]] / vals[bot[0]]) if top and bot else 0
        ok &= chk("U3 FB divider %s/%s -> VOUT = %.3f V (3.2-3.4)" % (top[0] if top else "?", bot[0] if bot else "?", vout), 3.2 < vout < 3.4)
    else:
        ok &= chk("U3 FB divider present (2 resistors on FB)", False, ",".join(fbr))
    l1 = {netname(M, u3, "8"), netname(M, u3, "9")}
    l2 = {netname(M, u3, "6"), netname(M, u3, "7")}
    lref = [r for r, m in M.comps.items() if r.startswith("L") and {M.pinnet.get((r, "1")), M.pinnet.get((r, "2"))} == (l1 | l2)]
    ok &= chk("U3 L1 (8/9) and L2 (6/7) paired and bridged by the inductor %s" % (lref[0] if lref else "?"), len(l1) == 1 and len(l2) == 1 and bool(lref))
    ok &= chk("U3 GND 2 and PGND pad 15 on GND", is_gnd(netname(M, u3, "2")) and is_gnd(netname(M, u3, "15")))
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

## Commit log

2026-09-09 Initial scaffold
    [01_power.kicad_sch, 01_pwr_input.kicad_sch, 02_flow.kicad_sch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]
2026-09-10 Boards viewer: the brand's logo, bar and colours
2026-09-10 Paler ground
2026-09-10 Analytics: consent on the boards viewer; no second bar inside the embedded lesson
